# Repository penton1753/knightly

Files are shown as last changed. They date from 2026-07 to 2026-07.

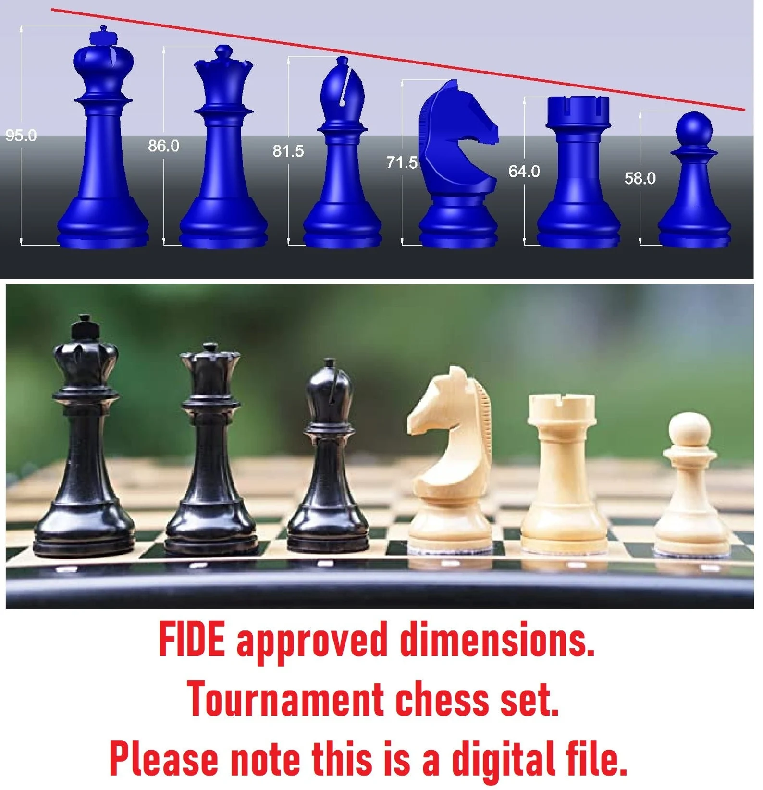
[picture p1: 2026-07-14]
Solidworks CAD/Modified FIDE SolidWorks Models_v4/FIDEReference.png

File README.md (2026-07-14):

# Knightly

This repository contains the asset files and non-application source code for Knightly, an automatic chessboard product by Chessington. The board is able to detect its own state, move pieces, and detect moves by human players.

This repository contains SOLIDWORKS CAD files for the board, pieces, clock, and other components, STEP files created in KiCAD for the design of the printed circuit boards, Arduino microcontroller code for the detection of chess pieces, and our final project poster.

## Folder Structure

CAD files related to the board are available under [Solidworks CAD](<./Solidworks CAD/>). CAD files related to the detection PCBs are available under [PCB CAD](<./PCB CAD/>). Microcontroller code for the detection system is available under [STMDetection](./STMDetection/). Application code is available under [knightly-app](./knightly-app/) (separate repository).

## License

With the exception of our [poster](./Poster.pdf) and our [application code](./knightly-app/), all asset and code files in this repository are available under [CC BY-SA 4.0](https://creativecommons.org/licenses/by-sa/4.0/). See [LICENSE.txt](./LICENSE.txt) for more information.

## Credits

Knightly was created by Corey Chow, Colin Kwok, Yakov Shur, Andrew Wang, and Yanis Yankauskas at UC Santa Barbara as a mechanical engineering capstone project.

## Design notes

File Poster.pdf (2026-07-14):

### Software

Knightly is built upon a base of open-source software. Libraries
like GRBL and WiringPi interface
with and control the physical
sensors and actuators, while Raylib powers the graphical user interface. The open source chess engine Stockfish is used for move generation in CPU play. All of this runs on off-the shelf components including a Raspberry Pi, Arduino Uno, and two STM32 microcontrollers.

Knightly is an Automatic Cyberphysical Chessboard product that translates physical, vocal, or touchscreen commands into chess movements. Knightly seeks to make chess more accessible to those with physical disabilities and to enhance the competitive chess experience.

## Corey Chow ・ Colin Kwok ・ Yakov Shur ・ Andrew Wang ・ Yanis Yankauskas

# Knightly: Automatic Chessboard

Acknowledgements:
We would like to thank Dr. Tal Margalith and David Adornetto for support with the New Venture Program and funding for this project; Prof. Paolo Luzzatto-Fegiz, Prof. Tyler Susko, Dr. Trevor Marks, and Dylan Guydish for design advice and guidance; and Dr. Brian Dincau, Josh Bowie, Sam Christos, and Carson Brown for assistance with fabrication.

# Final Product

# Conclusion

# Background

# Key Components

# Exploded View

The chessboard has 5 key components: a CoreXY gantry with a permanent magnet attached to a servo on the toolhead to transport pieces; an array of Hall effect sensors to detect piece location and identity; a wooden board top/enclosure; the chess pieces themselves; and a touch screen clock/display with a Raspberry Pi to control the electronics and run the chess engine. The Knightly chessboard is capable of facilitating player vs player, player vs CPU, and CPU vs CPU gameplay.

# Overview

### Gantry

The gantry of the chessboard is
the main system which moves
pieces. The system is controlled by a GRBL controller, which allows for precise motion of the toolhead in two dimensions. The toolhead uses a servo motor and permanent magnet to move pieces.

### Detection

The board’s detection system is comprised of 24 printed circuit boards. Each PCB has 16 Hall Effect sensors and one multiplexer, which detect magnetic field strength above every tile. The signals from the PCBs are processed by two STM32s, and are sent to the Raspberry Pi for determining board the state of the chess pieces.

# Knightly

# Rule the Board

### Chess Pieces

The chess pieces have their outer shells 3D printed using PETG. Inside each piece is a brass weight and a permanent magnet. The magnet allows for both movement of the piece by the toolhead, and detection by the Hall Effect sensors based on its height within the piece. Felt on the bottom of each piece allows for smooth moves and prevents scratching.

The Knightly Chessboard, fully assembled.

### Board and Enclosure

The board consists of two parts.
The bottom MDF base allows for
mounting the gantry and microcontrollers,
while the top plywood layer includes slots to mount the detection PCBs. Wood veneer is glued on top to serve as the tiles.

Testing was done to ensure functionality of the board. The gantry is able to move the pieces around the board consistently. The board is able to detect piece position and color, allowing for deduction of players’ physical moves. Players are able to play against either the board or other players. This board prototype demonstrates functionality both for chess players with disabilities and in competitive settings. Further design and testing will be done to send commands via voice control, and there is potential for future integration with online chess services.

Gantry and
Toolhead

Detection PCBs

Board Top
and Pieces

Enclosure

GRBL Controller

STM32

STM32

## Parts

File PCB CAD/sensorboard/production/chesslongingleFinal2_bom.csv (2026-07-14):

Designator | Footprint | Quantity | Value | LCSC Part #
FPC1, FPC2 | FPC-SMD_18P-P0.50_HDGC_0.5K-HX-18PWB | 2 | ~
JP1, JP10, JP11, JP12, JP2, JP3, JP4, JP5, JP6, JP7, JP8, JP9 | SolderJumper-2_P1.3mm_Open_RoundedPad1.0x1.5mm | 12 | Jumper_2_Open
U1 | SOP65P780X200-24N | 1 | CD74HC4067SM96E4
U10, U11, U12, U13, U14, U15, U16, U17, U2, U3, U4, U5, U6, U7, U8, U9 | SOT95P237X112-3N | 16 | DRV5053VAQDBZR

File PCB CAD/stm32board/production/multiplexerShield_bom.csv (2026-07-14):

Designator | Footprint | Quantity | Value | LCSC Part #
3V3, 5V1 | SolderJumper-2_P1.3mm_Open_RoundedPad1.0x1.5mm | 2 | Jumper_2_Open
FPC1, FPC2 | FPC-SMD_18P-P0.50_HDGC_0.5K-HX-18PWB | 2 | ~
J3 | PinHeader_1x01_P1.00mm_Vertical | 1 | Conn_01x01_Pin
J4, J5 | PinSocket_1x20_P2.54mm_Vertical | 2 | Conn_01x20
U2, U3 | SOP65P780X200-24N | 2 | CD74HC4067SM96E4
VBAT1, VP1, VREF1 | PinHeader_1x01_P2.54mm_Vertical | 3 | Conn_01x01_Pin

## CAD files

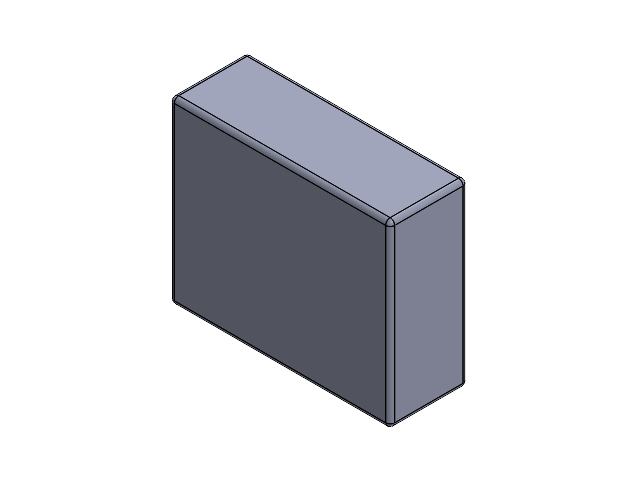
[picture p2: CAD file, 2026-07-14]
Solidworks CAD/Chess Piece Carrying Case/Carrying Case Assembly.SLDASM
Carrying Case Slot x 2
Chess Piece Carrying Case Housing
Pawn_Modified
King_Modified
Knight_Modified
Queen_Modified
Rook_Modified
Bishop_Modified

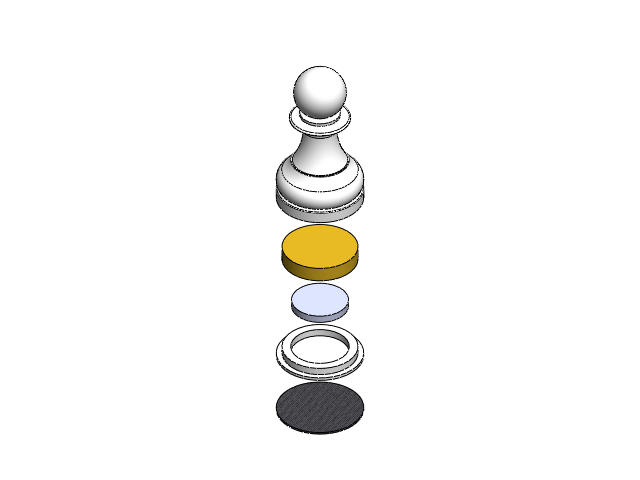
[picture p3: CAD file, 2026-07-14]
Solidworks CAD/Modified FIDE SolidWorks Models_v4/Pawn/PawnAssem_V4.SLDASM
Pawn_V4
Pawn_Felt
BrassWeight
Magnet
PieceBase

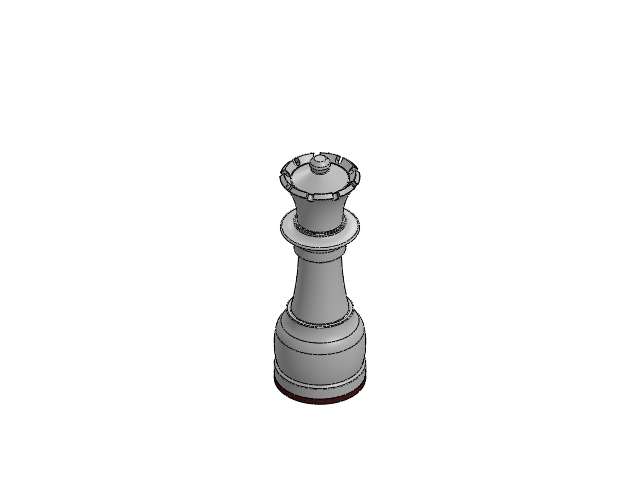
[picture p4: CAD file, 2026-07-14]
Solidworks CAD/Modified FIDE SolidWorks Models_v4/Queen/QueenAssem_V4.SLDASM
Queen_Felt
Queen_Modified_V3
PotMagnetShell
Magnet x 2

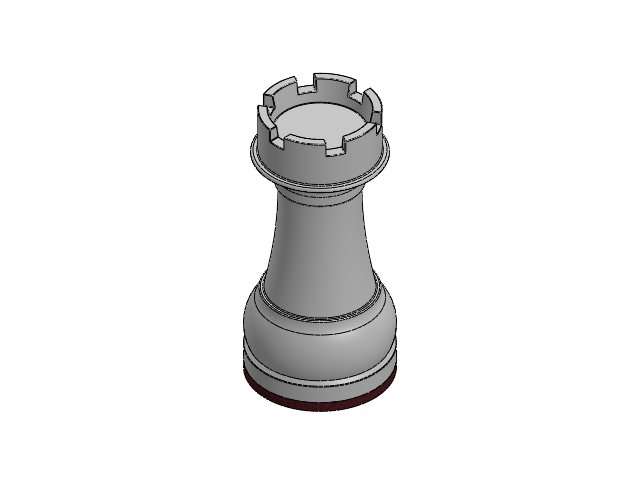
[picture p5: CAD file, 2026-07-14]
Solidworks CAD/Modified FIDE SolidWorks Models_v4/Rook/RookAssem_V4.SLDASM
Rook_V3
Rook_Felt
PotMagnetShell
Magnet x 2

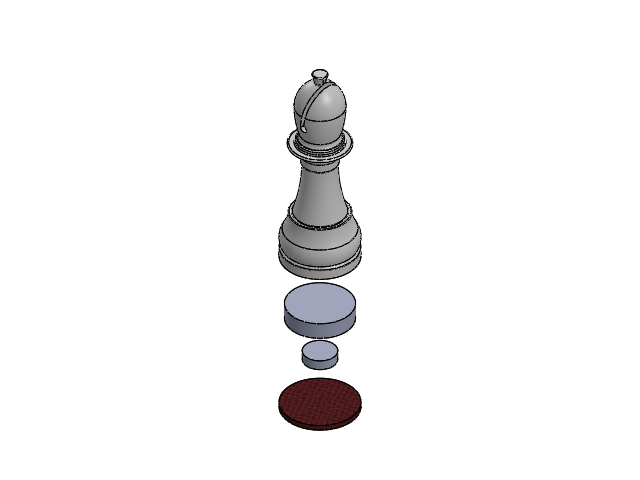
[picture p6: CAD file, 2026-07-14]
Solidworks CAD/Modified FIDE SolidWorks Models_v4/Bishop/BishopAssem_V4.SLDASM
Bishop_V3
Bishop_Felt
PotMagnetShell
Magnet x 2

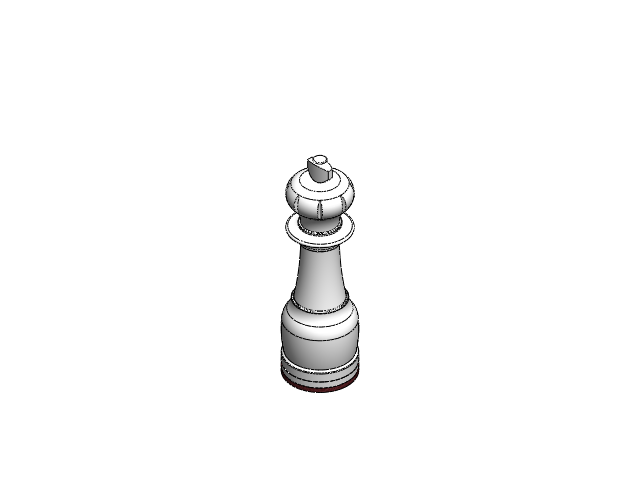
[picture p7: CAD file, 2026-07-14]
Solidworks CAD/Modified FIDE SolidWorks Models_v4/King/KingAssem_V4.SLDASM
King_Felt
King_V3
PotMagnetShell
Magnet x 3
Magnet Spacer

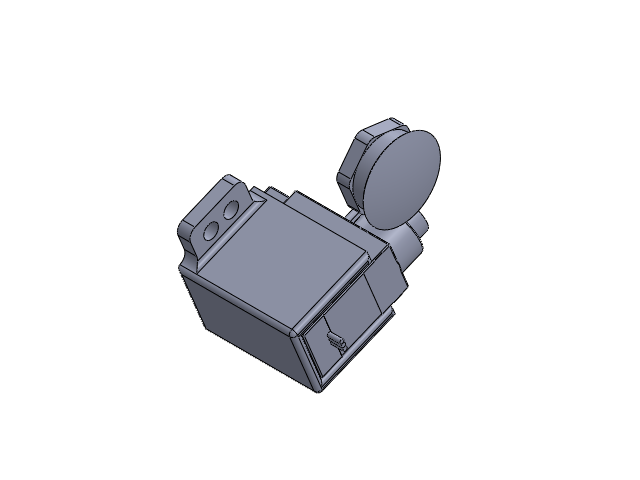
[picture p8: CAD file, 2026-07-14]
Solidworks CAD/Toolhead Servo L-Shaped Arm/L-Arm Assembly.SLDASM
Tower Pro MG90S Micro servo
Servo_LshapeArm
Vertical_servo_Larm_Housing
12x3mm Magnet
Magnet Hat

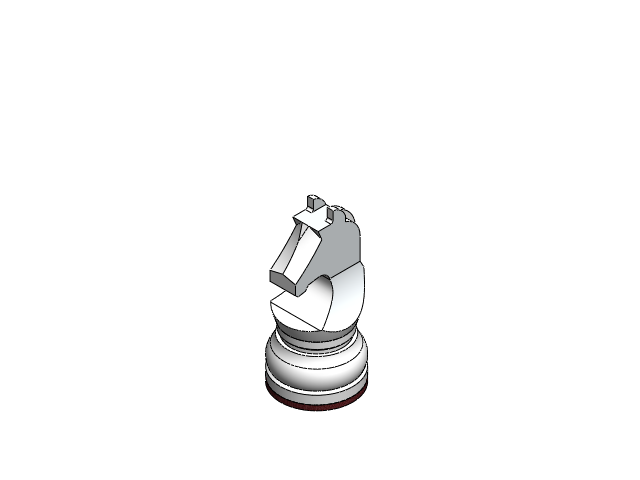
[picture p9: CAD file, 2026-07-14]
Solidworks CAD/Modified FIDE SolidWorks Models_v4/Knight/KnightAssem_V4.SLDASM
Knight_V3
Knight_Felt
PotMagnetShell
Magnet x 2

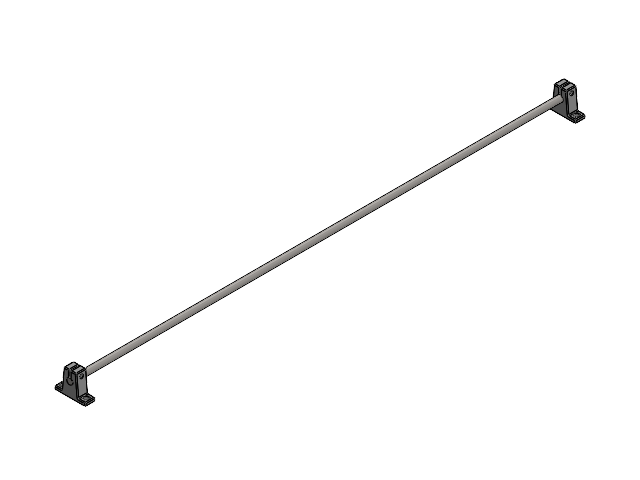
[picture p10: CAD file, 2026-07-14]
Solidworks CAD/MasterAssembly_v1/y axis.SLDASM
rod mount 61815K33_Base-Mounted Shaft Support x 2
rod 8x550mm

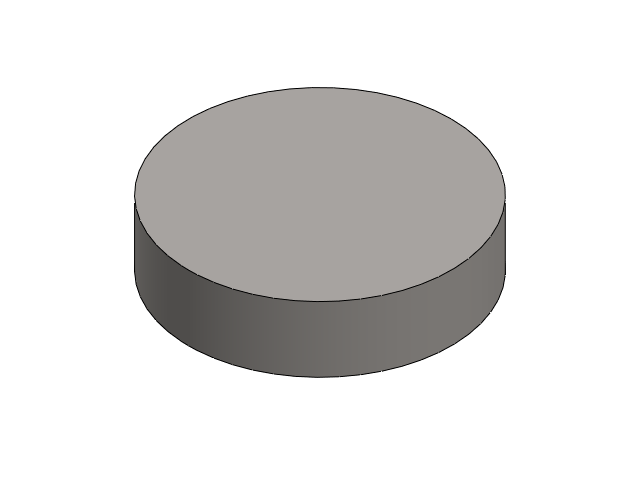
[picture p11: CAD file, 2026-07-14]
Solidworks CAD/Modified FIDE SolidWorks Models_v4/PotMagnet.SLDASM
PotMagnetShell
Magnet x 2

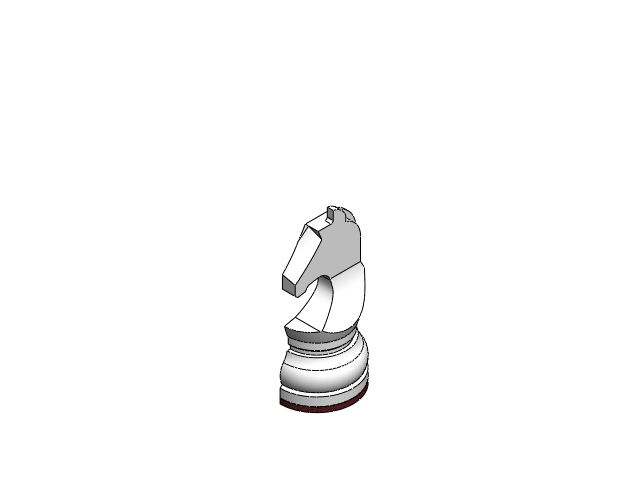
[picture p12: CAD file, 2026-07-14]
Solidworks CAD/MasterAssembly_v1/KnightAssem.SLDASM
Knight_Modified
Knight_Felt
PotMagnetShell
Magnet x 2

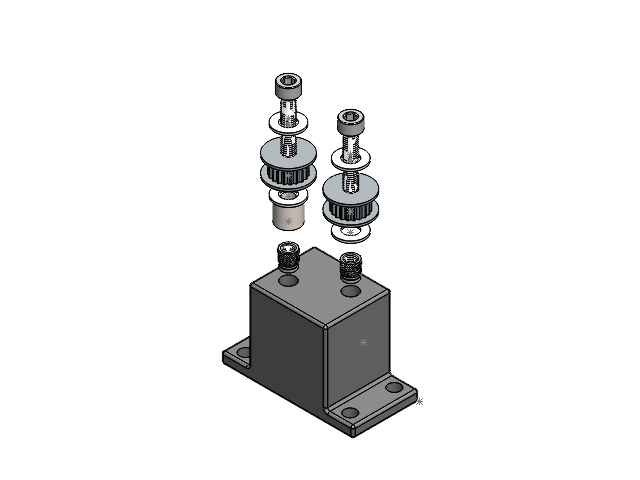
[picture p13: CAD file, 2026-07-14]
Solidworks CAD/MasterAssembly_v1/high idler.SLDASM
idler mount high v2.4
m5x9 spacer
m5 washer x 4
tooth idler pulley x 2
94459A775_Heat-Set Inserts for Plastic x 2
m5x25 91290A252_Black-Oxide Alloy Steel Socket Head Screw x 2
Part1^high idler

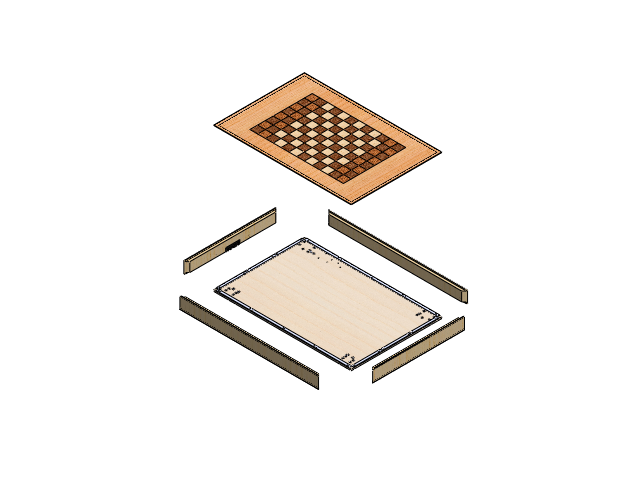
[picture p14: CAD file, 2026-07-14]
Solidworks CAD/MasterAssembly_v1/Enclosure_v2.SLDASM
BottomBoard_v2
LongWall_passthroughs _v2
ShortWall_v2
TopBoard_v2
95596A203_Zinc Alloy Tapping Inserts for Softwood x 27
91420A326_Steel Phillips Flat Head Screws
LongWall_v2
ShortWall_passthroughs_v2
USB Port
Enclosure_LowerShim_LS x 8
Enclosure_LowerShim_SS x 6

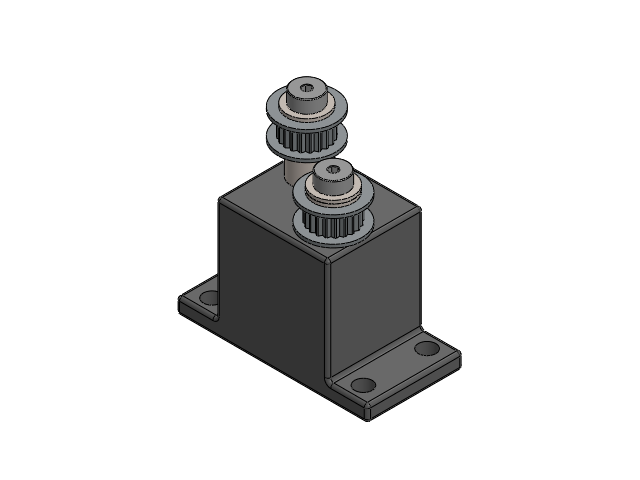
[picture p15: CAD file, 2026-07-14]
Solidworks CAD/MasterAssembly_v1/low idler.SLDASM
idler mount low v2.4
m5x9 spacer
m5 washer x 5
94180A353_Brass Tapered Heat-Set Inserts for Plastic(1) x 2
tooth idler pulley x 2
92981A034_Alloy Steel Shoulder Screws(1)
92981A042_Alloy Steel Shoulder Screws(1)

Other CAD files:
Solidworks CAD/MasterAssembly_v1/MagElev_Assemv3.SLDASM
Solidworks CAD/MasterAssembly_v1/MirrorESP32_Multiplexer_Shield.SLDASM
Solidworks CAD/MasterAssembly_v1/RookAssem.SLDASM
Solidworks CAD/MasterAssembly_v1/KingAssem.SLDASM
PCB CAD/sensorboard/10051922-1810ELF--3DModel-STEP-533217.STEP
PCB CAD/sensorboard/CD74HC4067SM96E4.STEP
PCB CAD/sensorboard/DRV5053VAQDBZR.STEP
Solidworks CAD/Chess Clock Files/Chess Clock Housing.SLDPRT
Solidworks CAD/Chess Clock Files/Chess Clock Housing.STL
Solidworks CAD/Chess Clock Files/Clock Button Nut.SLDPRT
Solidworks CAD/Chess Clock Files/Clock Button Washer.SLDPRT
Solidworks CAD/Chess Clock Files/Clock Button Washer.STL
Solidworks CAD/Chess Clock Files/Clock Button.SLDPRT
Solidworks CAD/Chess Clock Files/Clock Dpad Button Array.SLDPRT
Solidworks CAD/Chess Clock Files/Clock Housing Backboard.DXF
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

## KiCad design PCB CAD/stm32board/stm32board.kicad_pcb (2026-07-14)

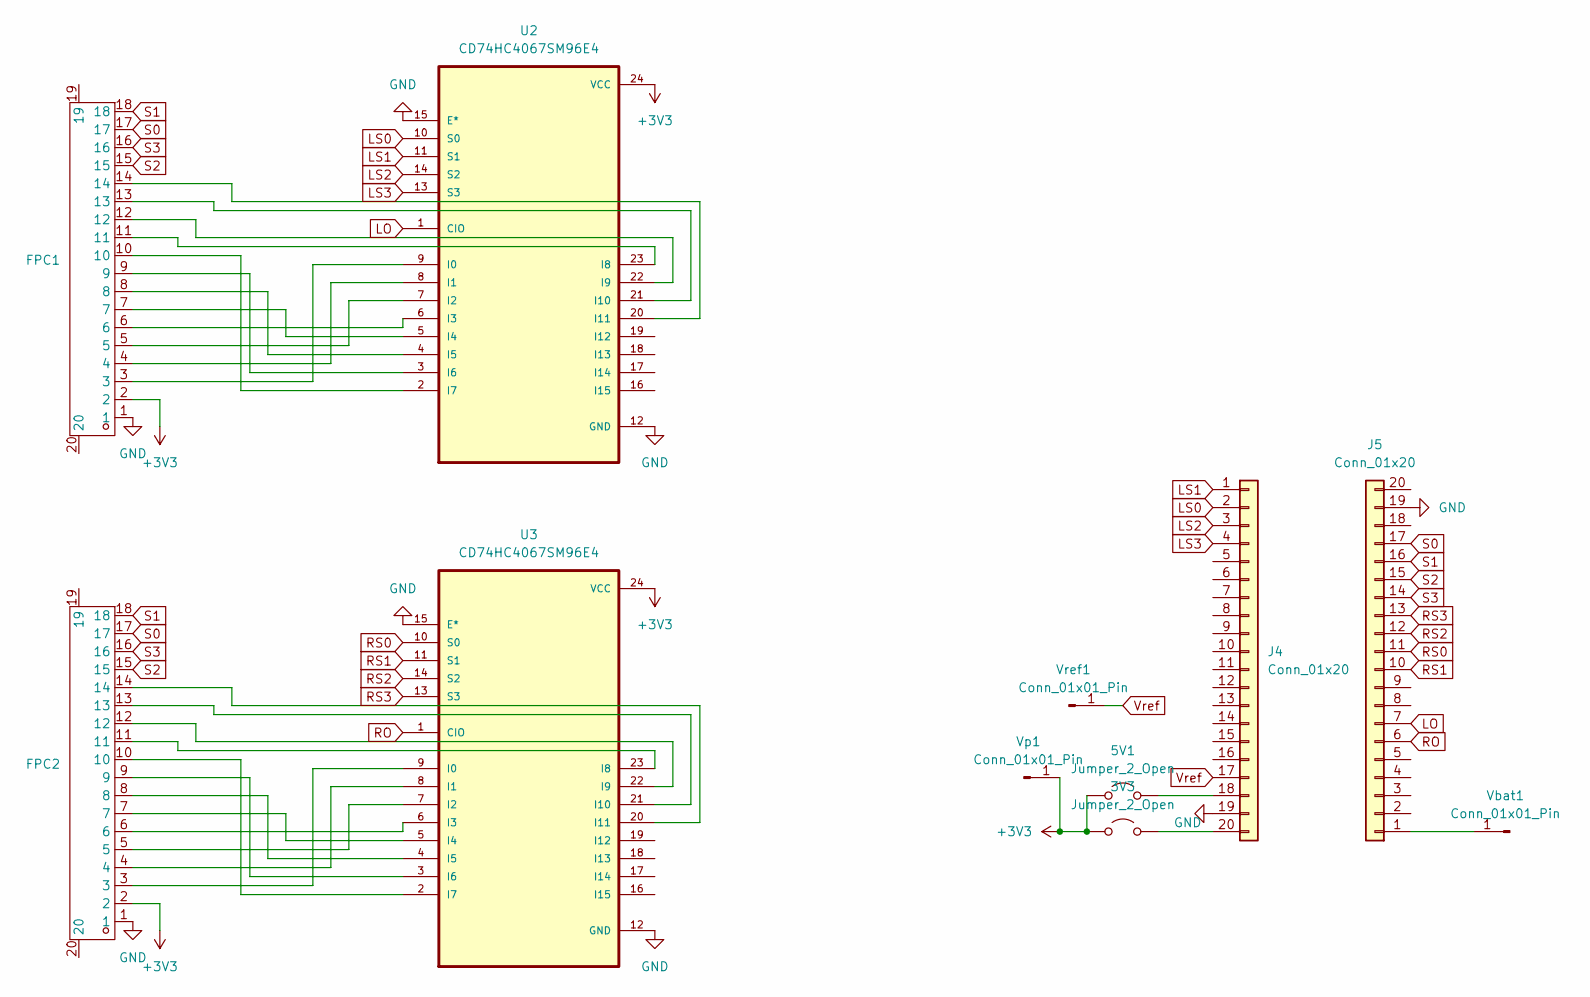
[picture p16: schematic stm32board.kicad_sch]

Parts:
3V3, 5V1: Jumper_2_Open; SolderJumper-2_P1.3mm_Open_RoundedPad1.0x1.5mm
FPC1, FPC2: FPC-SMD_18P-P0.50_HDGC_0.5K-HX-18PWB; Manufacturer Part 0.5K-HX-18PWB; LCSC Part Name 翻盖式 双侧触点/上下接 P数:18P 间距:0.5mm
J4, J5: Conn_01x20; PinSocket_1x20_P2.54mm_Vertical
U2, U3: CD74HC4067SM96E4; SOP65P780X200-24N; DigiKey_Part_Number 296-52634-1-ND
Vbat1: Conn_01x01_Pin; PinHeader_1x01_P2.54mm_Vertical
Vp1: Conn_01x01_Pin; PinHeader_1x01_P2.54mm_Vertical
Vref1: Conn_01x01_Pin; PinHeader_1x01_P2.54mm_Vertical

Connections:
+3V3: 3V3.1 (A), 5V1.1 (A), FPC1.2, FPC2.2, U2.24 (VCC), U3.24 (VCC), Vp1.1
GND: FPC1.1, FPC2.1, J4.19, J5.19, U2.12 (GND), U2.15 (E*), U3.12 (GND), U3.15 (E*)
LO: J5.7, U2.1 (CIO)
LS0: J4.2, U2.10 (S0)
LS1: J4.1, U2.11 (S1)
LS2: J4.3, U2.14 (S2)
LS3: J4.4, U2.13 (S3)
unnamed: 3V3.2 (B), J4.20
unnamed: 5V1.2 (B), J4.18
unnamed: J5.1, Vbat1.1
unnamed: FPC1.3, U2.9 (I0)
unnamed: FPC1.4, U2.8 (I1)
unnamed: FPC1.5, U2.7 (I2)
unnamed: FPC1.6, U2.6 (I3)
unnamed: FPC1.7, U2.5 (I4)
unnamed: FPC1.8, U2.4 (I5)
unnamed: FPC1.9, U2.3 (I6)
unnamed: FPC1.10, U2.2 (I7)
unnamed: FPC1.11, U2.23 (I8)
unnamed: FPC1.12, U2.22 (I9)
unnamed: FPC1.13, U2.21 (I10)
unnamed: FPC1.14, U2.20 (I11)
unnamed: FPC2.3, U3.9 (I0)
unnamed: FPC2.4, U3.8 (I1)
unnamed: FPC2.5, U3.7 (I2)
unnamed: FPC2.6, U3.6 (I3)
unnamed: FPC2.7, U3.5 (I4)
unnamed: FPC2.8, U3.4 (I5)
unnamed: FPC2.9, U3.3 (I6)
unnamed: FPC2.10, U3.2 (I7)
unnamed: FPC2.11, U3.23 (I8)
unnamed: FPC2.12, U3.22 (I9)
unnamed: FPC2.13, U3.21 (I10)
unnamed: FPC2.14, U3.20 (I11)
RO: J5.6, U3.1 (CIO)
RS0: J5.11, U3.10 (S0)
RS1: J5.10, U3.11 (S1)
RS2: J5.12, U3.14 (S2)
RS3: J5.13, U3.13 (S3)
S0: FPC1.17, FPC2.17, J5.17
S1: FPC1.18, FPC2.18, J5.16
S2: FPC1.15, FPC2.15, J5.15
S3: FPC1.16, FPC2.16, J5.14
Vref: J4.17, Vref1.1

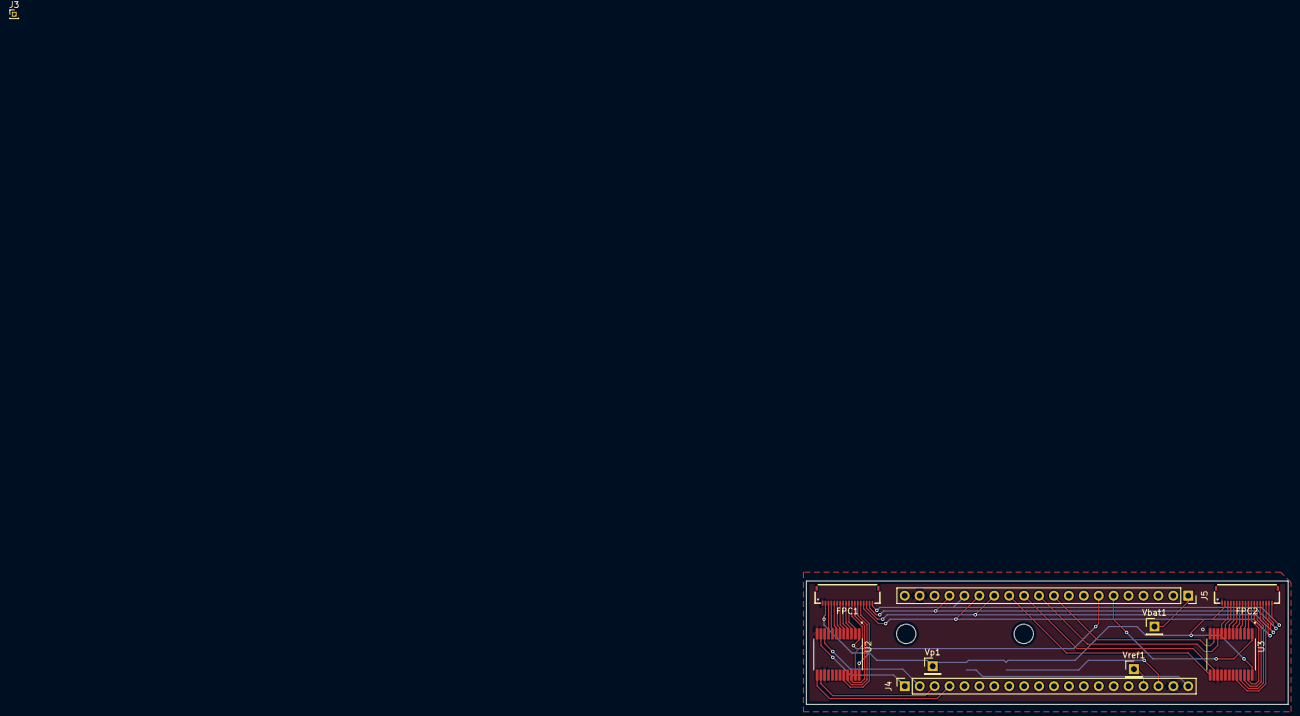
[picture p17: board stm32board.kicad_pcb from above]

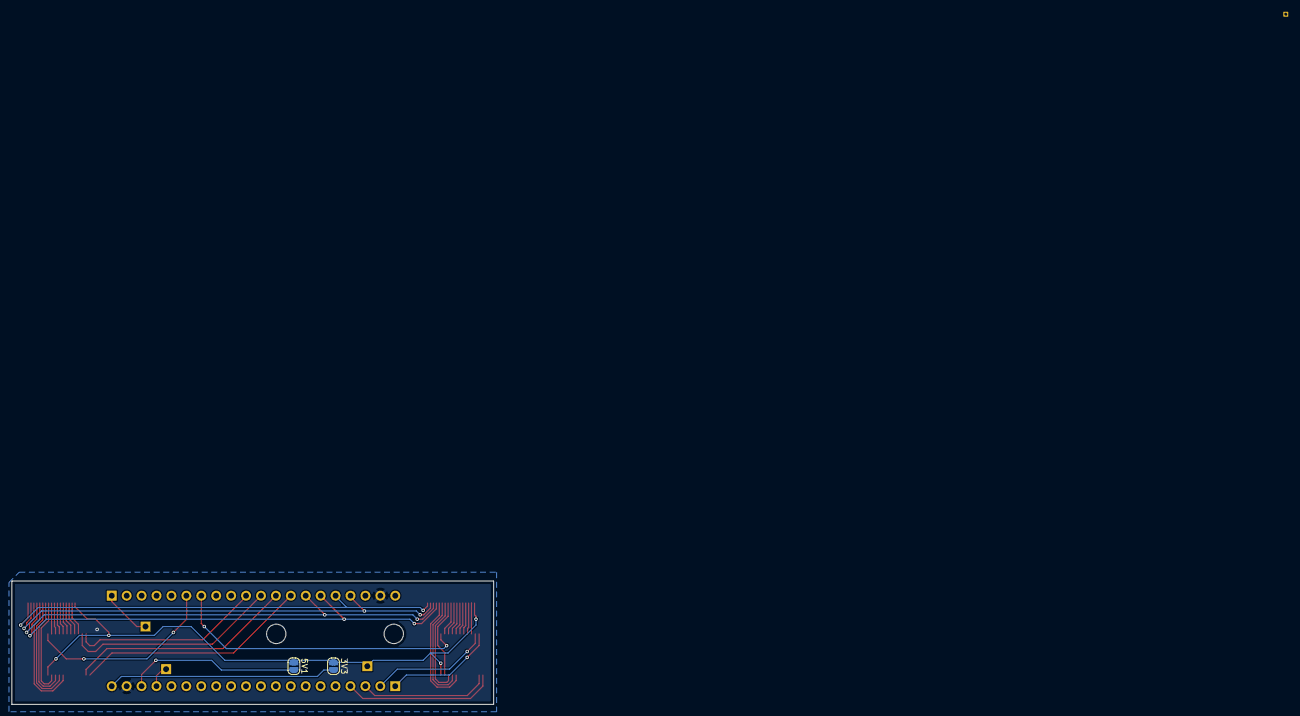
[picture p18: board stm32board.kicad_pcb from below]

Board: 2 copper layers, 82.0 x 21.0 mm, 12 parts (2 on the bottom side), 44 nets.

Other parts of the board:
J3: Conn_01x01_Pin; PinHeader_1x01_P1.00mm_Vertical

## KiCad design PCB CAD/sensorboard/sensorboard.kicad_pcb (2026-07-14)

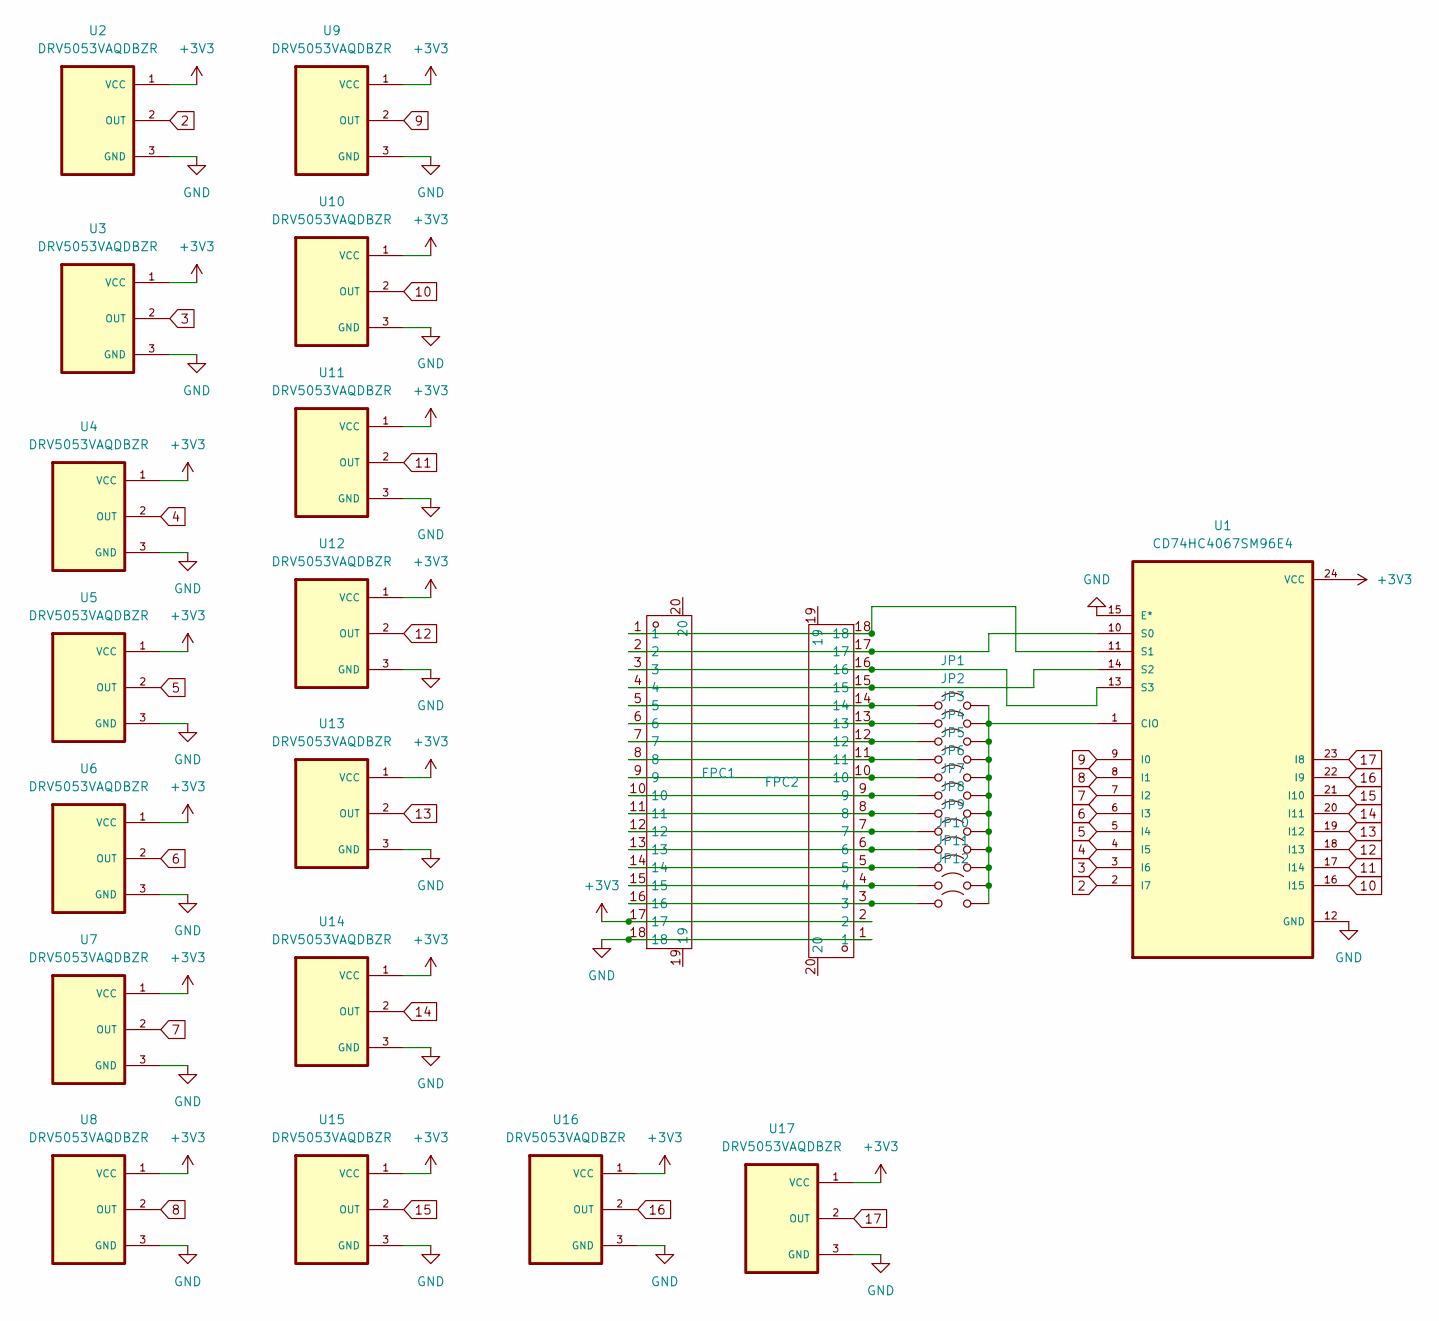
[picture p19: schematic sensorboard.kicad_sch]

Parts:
FPC1, FPC2: FPC-SMD_18P-P0.50_HDGC_0.5K-HX-18PWB; Manufacturer Part 0.5K-HX-18PWB; LCSC Part Name 翻盖式 双侧触点/上下接 P数:18P 间距:0.5mm
JP1, JP2, JP3, JP4, JP5, JP6, JP7, JP8, JP9, JP10, JP11, JP12: Jumper_2_Open; SolderJumper-2_P1.3mm_Open_RoundedPad1.0x1.5mm
U1: CD74HC4067SM96E4; SOP65P780X200-24N; DigiKey_Part_Number 296-52634-1-ND
U2, U3, U4, U5, U6, U7, U8, U9, U10, U11, U12, U13, U14, U15, U16, U17: DRV5053VAQDBZR; SOT95P237X112-3N; DigiKey_Part_Number 296-38460-1-ND

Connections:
2: U1.2 (I7), U2.2 (OUT)
3: U1.3 (I6), U3.2 (OUT)
4: U1.4 (I5), U4.2 (OUT)
5: U1.5 (I4), U5.2 (OUT)
6: U1.6 (I3), U6.2 (OUT)
7: U1.7 (I2), U7.2 (OUT)
8: U1.8 (I1), U8.2 (OUT)
9: U1.9 (I0), U9.2 (OUT)
10: U1.16 (I15), U10.2 (OUT)
11: U1.17 (I14), U11.2 (OUT)
12: U1.18 (I13), U12.2 (OUT)
13: U1.19 (I12), U13.2 (OUT)
14: U1.20 (I11), U14.2 (OUT)
15: U1.21 (I10), U15.2 (OUT)
16: U1.22 (I9), U16.2 (OUT)
17: U1.23 (I8), U17.2 (OUT)
+3V3: FPC1.17, FPC2.2, U1.24 (VCC), U2.1 (VCC), U3.1 (VCC), U4.1 (VCC), U5.1 (VCC), U6.1 (VCC), U7.1 (VCC), U8.1 (VCC), U9.1 (VCC), U10.1 (VCC), U11.1 (VCC), U12.1 (VCC), U13.1 (VCC), U14.1 (VCC), U15.1 (VCC), U16.1 (VCC), U17.1 (VCC)
GND: FPC1.18, FPC2.1, U1.12 (GND), U1.15 (E*), U2.3 (GND), U3.3 (GND), U4.3 (GND), U5.3 (GND), U6.3 (GND), U7.3 (GND), U8.3 (GND), U9.3 (GND), U10.3 (GND), U11.3 (GND), U12.3 (GND), U13.3 (GND), U14.3 (GND), U15.3 (GND), U16.3 (GND), U17.3 (GND)
unnamed: FPC1.5, FPC2.14, JP1.1 (A)
unnamed: JP1.2 (B), JP2.2 (B), JP3.2 (B), JP4.2 (B), JP5.2 (B), JP6.2 (B), JP7.2 (B), JP8.2 (B), JP9.2 (B), JP10.2 (B), JP11.2 (B), JP12.2 (B), U1.1 (CIO)
unnamed: FPC1.6, FPC2.13, JP2.1 (A)
unnamed: FPC1.7, FPC2.12, JP3.1 (A)
unnamed: FPC1.8, FPC2.11, JP4.1 (A)
unnamed: FPC1.9, FPC2.10, JP5.1 (A)
unnamed: FPC1.10, FPC2.9, JP6.1 (A)
unnamed: FPC1.11, FPC2.8, JP7.1 (A)
unnamed: FPC1.12, FPC2.7, JP8.1 (A)
unnamed: FPC1.13, FPC2.6, JP9.1 (A)
unnamed: FPC1.14, FPC2.5, JP10.1 (A)
unnamed: FPC1.15, FPC2.4, JP11.1 (A)
unnamed: FPC1.16, FPC2.3, JP12.1 (A)
unnamed: FPC1.2, FPC2.17, U1.10 (S0)
unnamed: FPC1.1, FPC2.18, U1.11 (S1)
unnamed: FPC1.4, FPC2.15, U1.14 (S2)
unnamed: FPC1.3, FPC2.16, U1.13 (S3)

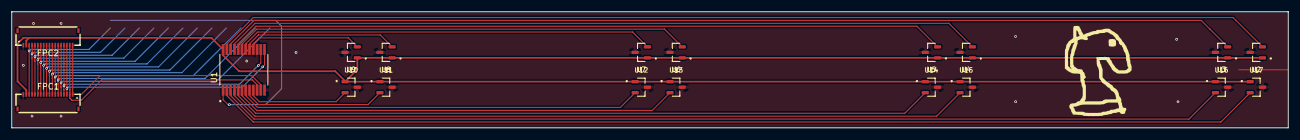
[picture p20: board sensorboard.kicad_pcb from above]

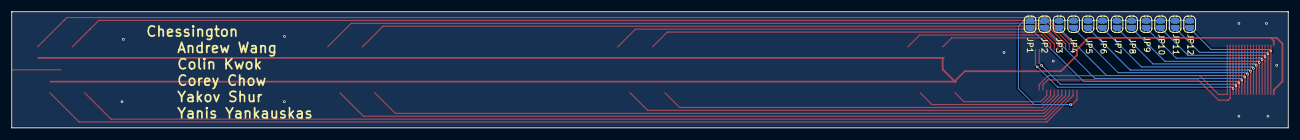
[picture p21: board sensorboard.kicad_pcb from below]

Board: 2 copper layers, 220.0 x 20.0 mm, 31 parts (12 on the bottom side), 35 nets.

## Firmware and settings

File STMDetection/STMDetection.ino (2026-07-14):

#include <Wire.h>
#include <CD74HC4067.h>

#define IGNORE_FAULTY true

#define IS_BOARD_1 false
#define REFERENCE 2275
#define BLACK_THRESHOLD 275
#define WHITE_THRESHOLD 110

#define DEBUG false

#define EMPTY 0
#define WHITE 1
#define BLACK 2

// Board Selection Multiplexer
CD74HC4067 muxL(PB13, PB12, PB14, PB15);
CD74HC4067 muxR(PA5, PA4, PA6, PA7);

// Sensor Selection Multiplexer
CD74HC4067 rib(PB10, PB_2, PB1, PB0);

const int signalPinL = PA1;
const int signalPinR = PA0;

// Constants for the 0.2V - 3.3V range
const int ADC_MIN = 0;     // Lower bound (0.2V)
const int ADC_MAX = 4095;  // Upper bound (3.3V)

int valArray[12][16];

void fillBuf(int buf[12][16]) {
#if IS_BOARD_1
  for (byte board = 0; board < 6; ++board) {
#else
  for (byte board = 6; board < 12; ++board) {
#endif
    muxL.channel(board);

    // Give the muxL some time to physically settle the connection
    delayMicroseconds(10);

    for (byte sensor = 0; sensor < 16; ++sensor) {
      rib.channel(sensor);
      delayMicroseconds(10);

      // Double read: First read clears the Sample & Hold capacitor
      analogRead(signalPinL);
      int raw = analogRead(signalPinL);
#if IS_BOARD_1
      valArray[board][sensor] = map(constrain(raw, ADC_MIN, ADC_MAX), ADC_MIN, ADC_MAX, 0, 4095);
#else
      valArray[board - 6][sensor] = map(constrain(raw, ADC_MIN, ADC_MAX), ADC_MIN, ADC_MAX, 0, 4095);
#endif
    }
  }

#if IS_BOARD_1
  for (byte board = 0; board < 6; ++board) {
#else
  for (byte board = 6; board < 12; ++board) {
#endif
    muxR.channel(board);

    // Give the muxR some time to physically settle the connection
    delayMicroseconds(10);

    for (byte sensor = 0; sensor < 16; ++sensor) {
      rib.channel(sensor);
      delayMicroseconds(10);

      // Double read: First read clears the Sample & Hold capacitor
      analogRead(signalPinR);
      int raw = analogRead(signalPinR);
#if IS_BOARD_1
      valArray[board + 6][sensor] = map(constrain(raw, ADC_MIN, ADC_MAX), ADC_MIN, ADC_MAX, 0, 4095);
#else
      valArray[board][sensor] = map(constrain(raw, ADC_MIN, ADC_MAX), ADC_MIN, ADC_MAX, 0, 4095);
#endif
    }
  }
}

void sendBinaryState(int buf[12][16]) {
  uint8_t state[96];

  for (int i = 0; i < 96; ++i) state[i] = 0;  // rasters rank then file

#if IS_BOARD_1  // Files E-j, L Ranks 1-4, R Ranks 5-8
  for (int board = 0; board < 12; ++board) {
    for (int sensor = 0; sensor < 16; ++sensor) {
      int file = 11 - board;
      if (board >= 6) file = 17 - board;

      int rank;
      if (sensor == 6 || sensor == 7 || sensor == 8 || sensor == 9) rank = 3;
      if (sensor == 4 || sensor == 5 || sensor == 10 || sensor == 11) rank = 2;
      if (sensor == 2 || sensor == 3 || sensor == 12 || sensor == 13) rank = 1;
      if (sensor == 0 || sensor == 1 || sensor == 14 || sensor == 15) rank = 0;

      if (board >= 6) rank = 7 - rank;

#if IGNORE_FAULTY
      // For the one really weird sensor
      if (board == 9 && sensor == 11) continue;
#endif

      if (state[file * 8 + rank] < WHITE && ((buf[board][sensor] - REFERENCE) < -WHITE_THRESHOLD || (buf[board][sensor] - REFERENCE) > WHITE_THRESHOLD))
        state[file * 8 + rank] = WHITE;
      if (state[file * 8 + rank] < BLACK && ((buf[board][sensor] - REFERENCE) < -BLACK_THRESHOLD || (buf[board][sensor] - REFERENCE) > BLACK_THRESHOLD))
        state[file * 8 + rank] = BLACK;
    }
  }
#else  // Files y-D, L Ranks 5-8, R Ranks 1-4
  for (int board = 0; board < 12; ++board) {
    for (int sensor = 0; sensor < 16; ++sensor) {
      int file = 5 - board;
      if (board >= 6) file = 11 - board;

      int rank;

      if (sensor == 6 || sensor == 7 || sensor == 8 || sensor == 9) rank = 3;
      if (sensor == 4 || sensor == 5 || sensor == 10 || sensor == 11) rank = 2;
      if (sensor == 2 || sensor == 3 || sensor == 12 || sensor == 13) rank = 1;
      if (sensor == 0 || sensor == 1 || sensor == 14 || sensor == 15) rank = 0;

      if (board < 6) rank = 7 - rank;

      if (state[file * 8 + rank] < WHITE && ((buf[board][sensor] - REFERENCE) < -WHITE_THRESHOLD || (buf[board][sensor] - REFERENCE) > WHITE_THRESHOLD))
        state[file * 8 + rank] = WHITE;
      if (state[file * 8 + rank] < BLACK && ((buf[board][sensor] - REFERENCE) < -BLACK_THRESHOLD || (buf[board][sensor] - REFERENCE) > BLACK_THRESHOLD))
        state[file * 8 + rank] = BLACK;
    }
  }
#endif

  Serial.write('T');
  for (int i = 0; i < 96; ++i) {
    if (state[i] == BLACK) Serial.write('B');
    else if (state[i] == WHITE) Serial.write('W');
    else Serial.write('_');
  }
  Serial.print("\n");
}

void setup() {
  // STM32 handles high baud rates easily. 115200 is recommended.
  Serial.begin(115200);

  pinMode(signalPinL, INPUT_ANALOG);  // Explicitly set for STM32 Analog
  pinMode(signalPinR, INPUT_ANALOG);  // Explicitly set for STM32 Analog

  // Set ADC Resolution to 12-bit (0-4095)
  analogReadResolution(12);
}

void loop() {
  if (Serial.available() > 0) {     // Check if data is waiting
    byte nextByte = Serial.read();  // Read the first available byte

    if (nextByte == 'T') {
      fillBuf(valArray);
      sendBinaryState(valArray);
    }
  }

  //Fast Output
  #if DEBUG
  for (int i = 0; i < 12; ++i)
  {
    Serial.print(i + 1);
    Serial.print("\t");
    Serial.print(": ");
    for (int j = 0; j < 16; ++j)
    {
      Serial.print((valArray[i][j] - REFERENCE) > 48 || (valArray[i][j] - REFERENCE) < -48 ? ((valArray[i][j]) - REFERENCE) : 0);
      // Serial.print((valArray[i][j] - REFERENCE) < -THRESHOLD || (valArray[i][j] - 2000) > THRESHOLD);
      Serial.print(j == 15 ? "" : "\t");
    }
    Serial.println();
  }
  Serial.println("---");
  delay(50);
  
  fillBuf(valArray);
  sendBinaryState(valArray);
  #endif
}
